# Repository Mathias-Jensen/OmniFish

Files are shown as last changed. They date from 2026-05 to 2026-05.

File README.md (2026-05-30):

# OmniFish

This repository contains the design files, control code, experimental protocols, datasets, analysis scripts, and CFD simulations developed for **OmniFish** — a soft robotic fish platform designed to span the full Body–Caudal Fin (BCF) locomotion range.

OmniFish was developed as part of a research project investigating how different fish-inspired body shapes and caudal fin configurations influence swimming kinematics, locomotion performance, and hydrodynamic behavior.

## Repository Structure

```text
OmniFish/
│
├── cfd-simulation/                 # CFD simulations of analyzed fish-inspired bodies
│   ├── average/                    # Average body simulation files
│   ├── boxfish/                    # Boxfish-inspired body simulation files
│   ├── eel/                        # Eel-inspired body simulation files
│   ├── mackerel/                   # Mackerel-inspired body simulation files
│   ├── trout/                      # Trout-inspired body simulation files
│   └── tuna/                       # Tuna-inspired body simulation files
│
├── data-and-data-analysis/          # Experimental data and MATLAB analysis scripts
│   ├── data/                       # Raw and experimental datasets
│   ├── KinematicResults.csv        # Kinematic analysis results
│   ├── fin_results.csv             # Fin experiment results
│   ├── swimming_results.csv        # Swimming performance results
│   ├── pairwise_statistics.csv     # Pairwise statistical comparisons
│   ├── within_mode_frequency_statistics.csv
│   ├── drag_simulation.mlx         # Drag simulation analysis
│   ├── kinematic_anlysis.mlx       # Kinematic analysis workflow
│   ├── load_cell_calibration.mlx   # Load cell calibration
│   ├── locomotion_experiments.mlx  # Locomotion experiment analysis
│   ├── oscillating_fin_experiment.mlx
│   └── swim_fin_trim.mlx
│
├── design-files/                   # Mechanical design files for bodies, fins, robot, and setups
│   ├── bodies/                     # Fish-inspired body geometries
│   ├── caudal-fins/                # Caudal fin designs
│   ├── robot/                      # Robot components and assembly files
│   └── setups/                     # Experimental setup design files
│
├── experimental-protocols/          # Protocols for fabrication, testing, and experiments
│
├── fish-specimen-analysis/          # Analysis of biological fish specimens and reference geometries
│
├── robot-control-code/              # Code used to control the soft robotic fish
│
├── LICENSE                         # MIT License
└── README.md
```

## Project Overview

The goal of OmniFish is to provide a soft robotic platform for studying BCF swimming across a wide range of fish-like morphologies.

The repository includes:

* Design files for soft robotic fish bodies and caudal fins
* Robot assembly and experimental setup files
* Robot control code
* Experimental protocols
* Raw and processed experimental data
* MATLAB analysis workflows
* CFD simulations of six analyzed body geometries
* Fish specimen analysis used to inform the body designs

## CFD Simulations

The `cfd-simulation/` folder contains simulation files for six fish-inspired body geometries:

* Average body
* Boxfish
* Eel
* Mackerel
* Trout
* Tuna

These simulations were used to compare hydrodynamic behavior across different body shapes representative of the BCF locomotion range.

## Data and Analysis

The `data-and-data-analysis/` folder contains experimental datasets and MATLAB Live Scripts used for processing and analyzing the project results.

Included analysis files cover:

* Swimming kinematics
* Locomotion experiments
* Oscillating fin experiments
* Load cell calibration
* Drag simulation
* Fin trimming and swimming performance
* Statistical comparisons between modes and frequencies

## Design Files

The `design-files/` folder contains the physical design files for the OmniFish platform.

It is organized into:

* `bodies/` — fish-inspired body geometries
* `caudal-fins/` — caudal fin designs
* `robot/` — robot hardware and assembly components
* `setups/` — experimental setups and test fixtures

## Experimental Protocols

The `experimental-protocols/` folder contains procedures used during the project, including testing, calibration, and experimental workflows.

## Robot Control Code

The `robot-control-code/` folder contains the code used to actuate and control the OmniFish robot during experiments.

## Fish Specimen Analysis

The `fish-specimen-analysis/` folder contains files related to the biological reference data and specimen analysis used to inform the robotic body geometries.

## Software Requirements

Depending on the part of the repository being used, the following software may be required:

* MATLAB, for data analysis and `.mlx` live scripts
* Arduino IDE or compatible embedded development tools, for robot control code
* CFD software compatible with the included simulation files (OpenFoam)
* CAD software for viewing or modifying design files

## Example Workflow

1. Select or modify a fish-inspired body geometry from `design-files/bodies/`.
2. Select a caudal fin design from `design-files/caudal-fins/`.
3. Manufacture and assemble the robot using files in `design-files/robot/`.
4. Use the protocols in `experimental-protocols/` to run experiments.
5. Control the robot using code from `robot-control-code/`.
6. Analyze the collected data using scripts in `data-and-data-analysis/`.
7. Compare experimental results with CFD simulations in `cfd-simulation/`.

## License

This repository is licensed under the MIT License.

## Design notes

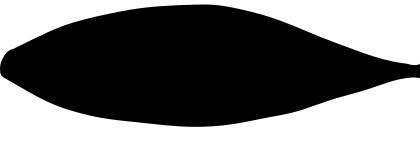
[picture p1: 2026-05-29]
fish-specimen-analysis/fish-annotations/tuna/thunniform-thunnus-thynnus-annotated-SL.png

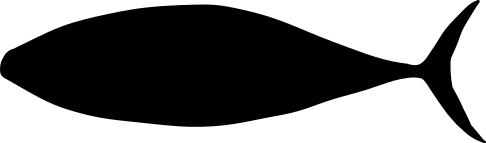
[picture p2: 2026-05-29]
fish-specimen-analysis/fish-annotations/tuna/thunniform-thunnus-thynnus-annotated.png

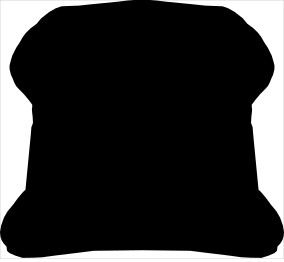
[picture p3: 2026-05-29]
fish-specimen-analysis/fish-annotations/boxfish/ostraciiform-ostracion-cubicum-annotated-front.png

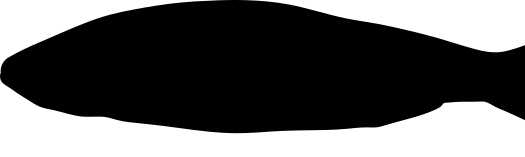
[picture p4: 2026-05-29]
fish-specimen-analysis/fish-annotations/trout/subcarangiform-oncorhynchus-mykiss-annotated-SL.png

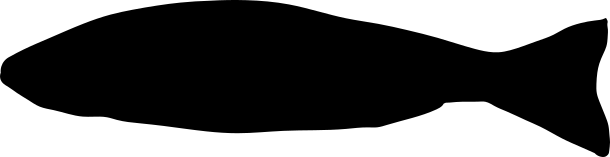
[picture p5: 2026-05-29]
fish-specimen-analysis/fish-annotations/trout/subcarangiform-oncorhynchus-mykiss-annotated.png

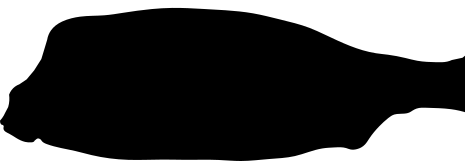
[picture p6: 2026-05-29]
fish-specimen-analysis/fish-annotations/boxfish/ostraciiform-ostracion-cubicum-annotated-SL.png

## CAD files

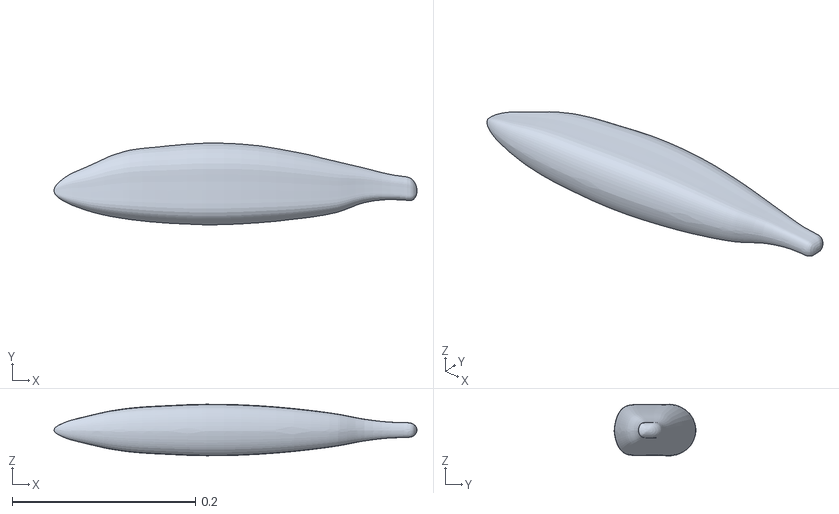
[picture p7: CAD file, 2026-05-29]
cfd-simulation/average/U_0p2/constant/triSurface/average-body-m.stl
0.396 x 0.0892 x 0.0563

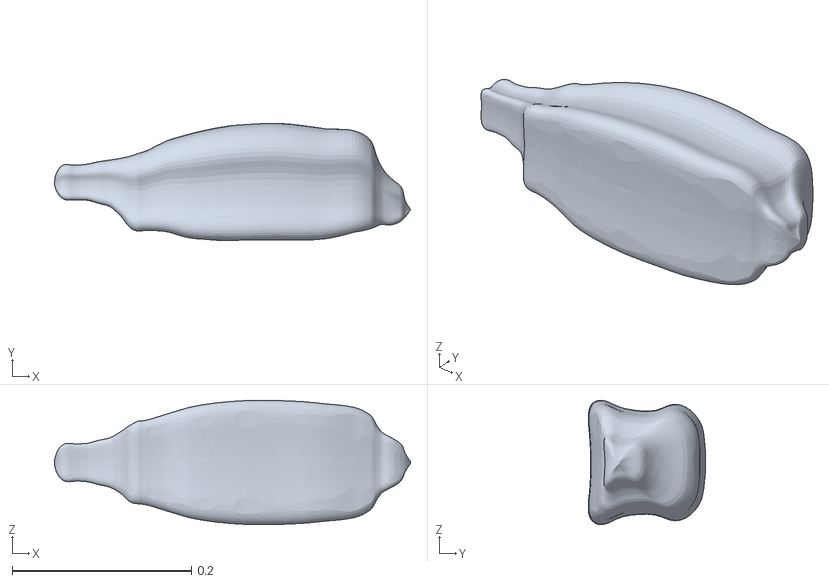
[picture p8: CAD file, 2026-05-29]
cfd-simulation/boxfish/U_0p2/constant/triSurface/boxfish-body-r.stl
0.398 x 0.131 x 0.139

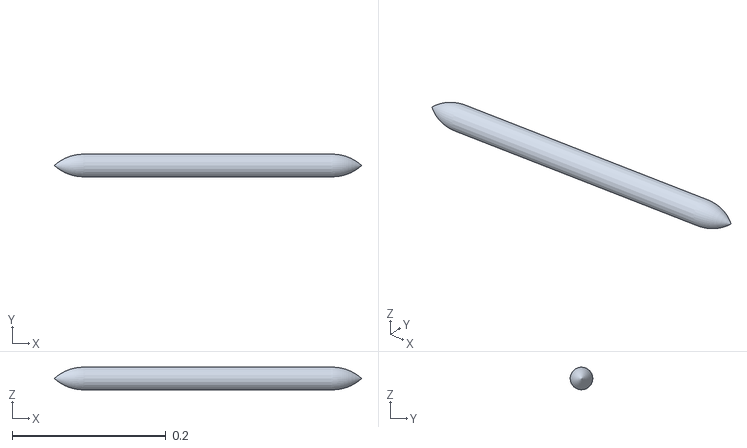
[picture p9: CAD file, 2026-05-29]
cfd-simulation/eel/U_0p2/constant/triSurface/eel-body-r.stl
0.4 x 0.0295 x 0.0295

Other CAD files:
cfd-simulation/boxfish/U_0p8/constant/triSurface/boxfish-body-m.stl
cfd-simulation/boxfish/U_1p2/constant/triSurface/boxfish-body-m.stl
cfd-simulation/eel/U_0p4/constant/triSurface/eel-body-scaled.stl
cfd-simulation/eel/U_0p6/constant/triSurface/eel-body-m-shifted.stl
cfd-simulation/eel/U_0p8/constant/triSurface/eel-body-scaled.stl
cfd-simulation/eel/U_1p0/constant/triSurface/eel-body-m.stl
cfd-simulation/eel/U_1p2/constant/triSurface/eel-body-m.stl
cfd-simulation/average/U_0p2/constant/triSurface/average-body-m_.stl
cfd-simulation/average/U_0p2/constant/triSurface/average-body.stl
cfd-simulation/average/U_0p4/constant/triSurface/average-body-m_.stl
cfd-simulation/average/U_0p4/constant/triSurface/average-body.stl
cfd-simulation/average/U_0p6/constant/triSurface/average-body-m_.stl
cfd-simulation/average/U_0p6/constant/triSurface/average-body.stl
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

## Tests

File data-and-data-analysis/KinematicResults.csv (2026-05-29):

Mode | HeadAmp | TailAmp | HeadTailRatio | MinAmp | MinAmpLocation | MaxAmp | MaxAmpLocation
anguilliform | 0.0282436772139726 | 0.488052727671527 | 0.0578701349518558 | 0.000144048898051361 | 0.331531439775692 | 0.50522105657655 | 1.10710087361025
subcarangiform | 0.0106068013899575 | 0.471286476830839 | 0.0225060592896339 | 6.02653705563993e-05 | 0.250051655004815 | 0.487572842297228 | 1.10498485189685
carangiform | 0.0127676578993266 | 0.411906095803775 | 0.0309965257358292 | 7.39281999602879e-05 | 0.287462581783511 | 0.427943304510525 | 1.12110685822132
thunniform | 0.0124125704586608 | 0.28515054918977 | 0.0435298844555272 | 6.36318452855874e-05 | 0.272506339116033 | 0.2984594122229 | 1.11524327440523
ostraciiform | 0.0102349853231907 | 0.337413636943945 | 0.0303336445316555 | 0.000119461955351604 | 0.300857605386007 | 0.358536053907394 | 1.10787518773132

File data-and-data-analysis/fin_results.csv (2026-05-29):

FinID | FinType | Material | Thickness | Frequency | Amplitude | ExperimentID | Thrust | MaxThrust | MaxDrag | PosPeriod | NegPeriod
1 | 1 | 1 | 1 | 0.6 | 0.15 | 1 | -0.000443319491055559 | 0.0190478267593949 | -0.019239262204213 | 0.414856594263771 | 0.585143405736229
1 | 1 | 1 | 1 | 0.6 | 0.15 | 2 | 7.85019805170302e-05 | 0.0255124544728656 | -0.020137536214513 | 0.52538101524061 | 0.47461898475939
1 | 1 | 1 | 1 | 0.6 | 0.15 | 3 | 0.000198256709825532 | 0.0181569156508186 | -0.0186575929680351 | 0.538821552862115 | 0.461178447137886
1 | 1 | 1 | 1 | 0.6 | 0.15 | 4 | -8.14734719963359e-05 | 0.0163750934336661 | -0.0160216741509251 | 0.539541581663266 | 0.460458418336733
1 | 1 | 1 | 1 | 0.6 | 0.15 | 5 | 6.05484463606166e-05 | 0.0222506890092352 | -0.018981560643881 | 0.552502100084003 | 0.447497899915997
1 | 1 | 1 | 1 | 0.6 | 0.15 | 6 | 9.04144539407534e-05 | 0.0222286003040639 | -0.0204762296938064 | 0.55646225849034 | 0.44353774150966
1 | 1 | 1 | 1 | 0.6 | 0.18 | 1 | 0.00027796036397082 | 0.0298271148829953 | -0.0290760989071707 | 0.534621384855394 | 0.465378615144606
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

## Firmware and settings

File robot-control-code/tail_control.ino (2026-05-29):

#include "isr_servo.h"

ISRServo finServo;

// ---- USER SETTINGS ----

// Servo pin
const int SERVO_PIN = 9;

// PWM frame frequency
const float PWM_FREQUENCY_HZ = 50.0f;

// Pulse width limits
const int PULSE_MIN_US = 1000;
const int PULSE_MAX_US = 2000;

// Safe mechanical limits
float MIN_ANGLE = 0;
float MAX_ANGLE = 100;

// Motion defaults
float centerAngle   = 50.0;   // servo mid-angle
float amplitudeDeg  = 24.0;   // swing around center
float frequencyHz   = 0.6;    // tail beat frequency (full cycles per second)

// How many command updates per cycle
const int UPDATES_PER_CYCLE = 30;
unsigned long UPDATE_INTERVAL_US;

// ---- Experiment State ----
float angle = centerAngle;   // used by PWM generator

bool experimentRunning       = false;

unsigned long experimentStartMs = 0;
unsigned long experimentStopMs  = 0;   // when to stop (in millis)

// Timing
unsigned long lastUpdateUs   = 0;

int numTailBeats = 5;  // default number of beats for next experiment

// Forward declarations
void startExperiment(int beats);
void stopExperiment();
void printCurrentSettings();
void updateUpdateInterval();

void setup() {
  finServo.begin(SERVO_PIN,PWM_FREQUENCY_HZ,PULSE_MIN_US,PULSE_MAX_US);
  finServo.writeAngle(angle);

  updateUpdateInterval();

  Serial.begin(115200);
  while (!Serial) { }            // wait for Serial on some boards

  Serial.println("=== Tail Beat Controller ===");
  Serial.println("Commands:");
  Serial.println("  f <value>  -> set frequency in Hz (e.g. f 1.5)");
  Serial.println("  a <value>  -> set amplitude in degrees (e.g. a 25)");
  Serial.println("  c <value>  -> set center angle (e.g. c 90)");
  Serial.println("  b <value>  -> set number of tail beats (e.g. b 10)");
  Serial.println("  go         -> start experiment with current beats");
  Serial.println("  <number>   -> start with that many beats (e.g. 8)");
  Serial.println();
  printCurrentSettings();
}

void loop() {
  // If no experiment is running, listen for commands
  if (!experimentRunning) {
    checkSerialCommand();
    return;
  }

  unsigned long nowUs = micros();
  unsigned long nowMs = millis();

  // Stop condition: reached total duration
  if (nowMs >= experimentStopMs) {
    stopExperiment();
    return;
  }

  // Time to update servo position?
  if (nowUs - lastUpdateUs >= UPDATE_INTERVAL_US) {
    lastUpdateUs = nowUs;

    // Time in seconds since experiment start
    float t = (nowMs - experimentStartMs) / 1000.0;

    // Sinusoidal angle: center + A * sin(2π f t)
    angle = centerAngle + amplitudeDeg * sin(2.0 * PI * frequencyHz * t);
    angle = constrain(angle, MIN_ANGLE, MAX_ANGLE);

    finServo.writeAngle(angle);
  }
}

// ---------------- Serial Command Handling ----------------

void checkSerialCommand() {
  if (Serial.available() == 0) return;

  String line = Serial.readStringUntil('\n');
  line.trim();
  if (line.length() == 0) return;

  char cmd = line.charAt(0);
  String argStr;
  float value;

  // If line starts with a letter, treat as command + value
  if ((cmd == 'f') || (cmd == 'F')) {
    argStr = line.substring(1);
    argStr.trim();
    value = argStr.toFloat();
    if (value > 0.0) {
      frequencyHz = value;
      updateUpdateInterval();
      Serial.print("Set frequencyHz = ");
      Serial.println(frequencyHz, 3);
      printCurrentSettings();
    } else {
      Serial.println("Invalid frequency.");
    }
    return;
  }

  if ((cmd == 'a') || (cmd == 'A')) {
    argStr = line.substring(1);
    argStr.trim();
    value = argStr.toFloat();
    if (value > 0.0) {
      // Ensure amplitude fits inside mechanical limits
      float maxAllowedAmp = (MAX_ANGLE - MIN_ANGLE) / 2.0;
      if (value > maxAllowedAmp) {
        Serial.print("Amplitude too large; limiting to ");
        Serial.println(maxAllowedAmp);
        amplitudeDeg = maxAllowedAmp;
      } else {
        amplitudeDeg = value;
      }
      Serial.print("Set amplitudeDeg = ");
      Serial.println(amplitudeDeg, 2);
      printCurrentSettings();
    } else {
      Serial.println("Invalid amplitude.");
    }
    return;
  }

  if ((cmd == 'c') || (cmd == 'C')) {
    argStr = line.substring(1);
    argStr.trim();
    value = argStr.toFloat();
    if (value >= 0.0 && value <= 180.0) {
      centerAngle = value;
      angle = centerAngle;
      Serial.print("Set centerAngle = ");
      Serial.println(centerAngle, 2);
      finServo.writeAngle(centerAngle);  // update immediately
      printCurrentSettings();
    } else {
      Serial.println("Invalid center angle (must be 0–180).");
    }
    return;
  }

  if ((cmd == 'b') || (cmd == 'B')) {
    argStr = line.substring(1);
    argStr.trim();
    int beats = argStr.toInt();
    if (beats > 0) {
      numTailBeats = beats;
      Serial.print("Set numTailBeats = ");
      Serial.println(numTailBeats);
      printCurrentSettings();
    } else {
      Serial.println("Invalid tail beat count.");
    }
    return;
  }

  // 'go' command (start with current numTailBeats)
  if (line.equalsIgnoreCase("go")) {
    startExperiment(numTailBeats);
    return;
  }

  // If it wasn't a lettered command, try to interpret as a bare number of beats
  int beats = line.toInt();
  if (beats > 0) {
    startExperiment(beats);
  } else {
    Serial.println("Unknown command. Use: f/a/c/b/go or a number for beats.");
  }
}

// ---------------- Experiment Control ----------------

void startExperiment(int beats) {
  if (beats <= 0 || frequencyHz <= 0.0) {
    Serial.println("Invalid beats or frequency; experiment not started.");
    return;
  }

  numTailBeats = beats;

  // Total experiment duration (s) = beats / frequency
  float durationSec = (float)numTailBeats / frequencyHz;

  experimentStartMs = millis();
  experimentStopMs  = experimentStartMs + (unsigned long)(durationSec * 1000.0);
  lastUpdateUs      = micros();

  experimentRunning = true;
}

void stopExperiment() {
  experimentRunning = false;
  angle = centerAngle;   // return to center
  finServo.writeAngle(angle);
  Serial.println("done");
}

// ---------------- Utility ----------------

void printCurrentSettings() {
  Serial.print("Current settings -> ");
  Serial.print("f = ");
  Serial.print(frequencyHz, 3);
  Serial.print(" Hz, A = ");
  Serial.print(amplitudeDeg, 1);
  Serial.print(" deg, center = ");
  Serial.print(centerAngle, 1);
  Serial.print(" deg, beats = ");
  Serial.println(numTailBeats);
}

void updateUpdateInterval() {
  float intervalSec = 1.0 / (frequencyHz * UPDATES_PER_CYCLE);
  UPDATE_INTERVAL_US = (unsigned long)(intervalSec * 1e6);

  // Clamp for safety
  UPDATE_INTERVAL_US = constrain(UPDATE_INTERVAL_US, 278, 20000);
}

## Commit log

2026-05-28 added design files
    [alu fasteners.stl, alu fasteners.stp, alu-profile-servo-mount.stl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]
2026-05-29 added data, data processing scripts, experimental protocols, robot control code, and cfd simulation files
    [KinematicResults.csv, average-body-m.stl, average-body-m_.stl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]
